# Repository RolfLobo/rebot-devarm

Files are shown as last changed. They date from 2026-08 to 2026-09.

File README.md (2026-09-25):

<div align="center">

# 🦾 reBot-DevArm

**The Open-Source Robotic Arm for Every Developer**

reBot-DevArm Banner

<a href="https://certification.oshwa.org/cn000024.html">OSHWA Certified</a>








**100% Open Source · Embodied AI · Full Hardware + Software Stack**

🌐 [Landing Page](https://279070161-sketch.github.io/reBot/) · 📚 [Tutorial Center](https://wiki.seeedstudio.com/robotics_page/) · ▶ [Online Demo](https://yang-ci.github.io/Rebot_Arm_AGV/)




[简体中文](README_zh.md) · [English](README.md) · [日本語](README_JP.md) · [français](README_Fr.md) · [Español](README_es.md)

</div>

---

## 📑 Contents

- [📖 Introduction](#introduction)
- [🛒 Get Your reBot Arm](#get-your-rebot-arm)
- [🚀 Try the Online Simulation](#try-the-online-simulation)
- [🗺️ Roadmap and Status](#roadmap-and-status)
- [⚙️ Hardware Specifications](#hardware-specifications)
- [🌟 Community Showcase](#community-showcase)
- [🧹 Optional Hardware](#optional-hardware)
- [🎓 Full-Stack Robotics Ecosystem](#full-stack-robotics-ecosystem)
- [🙌 Acknowledgments and Contributors](#acknowledgments-and-contributors)
- [📄 License](#license)
- [☎ Contact Us](#contact-us)

---

## 📖 Introduction

**reBot-DevArm** — the **reBot Arm B601-DM** and **reBot Arm B601-RS** — is a robotic arm project dedicated to lowering the barrier to learning Embodied AI. We believe in **true open source**: not just the code, but everything, released without reservation.

- 🦾 **Two arm models** — All design files for the **B601-DM (Damiao)** and **B601-RS (Robstride)**, two arms sharing the same appearance.
- 🛠️ **Hardware blueprints** — Source files for sheet-metal and 3D-printed parts.
- 🔩 **BOM list** — Detailed down to the spec and purchase link of every single screw.
- 💻 **Software & algorithms** — Python SDK, ROS1/2, Isaac Sim, LeRobot, and more.

## 🛒 Get Your reBot Arm

| Model | Official Store | Other Channels |
| :--- | :--- | :--- |
| **reBot Arm B601-DM** | [SeeedStudio Bazaar](https://www.seeedstudio.com/reBot-Arm-B601-DM-Assembled-Kit-with-Power-Supply-Bundle.html) | [Amazon](https://www.amazon.com/dp/B0H2TWVFSW) · [AliExpress](https://de.aliexpress.com/item/1005012108314029.html) |
| **reBot Arm B601-RS** | [SeeedStudio Bazaar](https://www.seeedstudio.com/reBot-Arm-B601-RS-Bundle-p-6898.html) | [AliExpress](https://www.aliexpress.us/item/3256812343811970.html?gatewayAdapt=deu2usa4itemAdapt) |

### B601-DM Kit Options

Five kit options are available at [SeeedStudio.com](https://www.seeedstudio.com/reBot-Arm-B601-DM-Bundle.html):

- **Arm Body Motor Kit** — Motors and wiring harnesses only.
- **Arm Body Structural Kit** — Mechanical structural components only.
- **Gripper Complete Kit** — Motors, wiring, and structure for the gripper.
- **Full Kit** — Complete arm body and gripper.
- **Pre-assembled Robotic Arm** — Fully assembled, ready to use.

> 💡 The kit does not include a power adapter or C-clamps as standard, since you may power it with batteries or mount it on a custom DIY base. Purchase a [power supply](https://www.seeedstudio.com/AC-DC-Power-Adapter-IEC-60320-C14-XT30-Female-24V-4-5A-1200mm-L190-W92-5-H36mm-p-6764.html) and [power cord](https://www.seeedstudio.com/reServer-AC-US-p-5052.html) separately, or see the Mean Well solution at the bottom of the [BOM](./hardware/reBot_B601_DM/readme.md#about-power-supply).

### B601-RS Kit Options

Two kit options are available at [SeeedStudio.com](https://www.seeedstudio.com/reBot-Arm-B601-RS-Assembled-Kit-with-Gripper-p-6865.html):

- **Full Kit** — Unassembled complete arm body and gripper.
- **Pre-assembled Robotic Arm** — Fully assembled, ready to use.

> 💡 We recommend the [Mean Well 48V 12.5A](https://www.amazon.com/sspa/click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) power supply for the RS model. For full performance, opt for a 48V 25A adapter.

### Leader Arm (Optional)

Purchase the [Leader Arm](https://www.seeedstudio.com/Star-Arm-102-p-6765.html?qid=P2U7IG_yskyak5m_1776415593315) and a [12V 10A power supply](https://www.seeedstudio.com/FY1209900-12V-10A-Power-Adapter-12V-10A-p-6496.html); the 12V DC adapter of the SO-ARM101 also works.

## 🚀 Try the Online Simulation

Experience the reBot Arm B601-RS MuJoCo digital twin directly in your browser — no installation required. Switch between the standard arm and AGV configurations, control joints and TCP, view the overhead and D405 wrist cameras, and run the automated put-away and stacking demos. The initial model download may take a moment; Chrome or Edge is recommended.

<p align="center">
  <a href="https://yang-ci.github.io/Rebot_Arm_AGV/"><strong>▶ Launch the reBot Arm Interactive Demo</strong></a>
</p>

## 🗺️ Roadmap and Status

We continuously maintain and adapt to mainstream robot development ecosystems. Below is our current progress and release plan.

### reBot Arm B601-DM

| Ecosystem | Status | Description | Documentation |
| :--- | :---: | :--- | :--- |
| Basic Motor Usage | ✅ Done | Motion control and API encapsulation | [Damiao Technology](https://wiki.seeedstudio.com/cn/damiao_series/) |
| STEP 3D Parts & BOM | ✅ Done | STEP files, parts BOM, and reference prices | [reBot Arm B601-DM BOM](./hardware/reBot_B601_DM/readme.md) |
| Real-Machine Performance Testing | ✅ Done | Performance under normal and extreme conditions | [Performance Testing](./hardware/reBot_B601_DM/performance_testing/Performance_Testing.md) |
| Assembly Video | ✅ Done | Ultra-detailed assembly steps and video | [Getting Started](https://wiki.seeedstudio.com/rebot_b601_dm_getting_started/) |
| Python SDK | ✅ Done | One-stop motor read/write & control (Robstride, Damiao, Mota, Gaoqing, Hexfellow…) | [Motorbridge](https://motorbridge.seeedstudio.com) · [Web UI](https://rebot-devarm.w0x7ce.eu/) |
| ROS2 Integration | ✅ Done | Kinematics, trajectory planning, gravity compensation | [ROS2 Guide](https://wiki.seeedstudio.com/rebot_arm_b601_dm_ros2_integration/) |
| Pinocchio Integration | ✅ Done | Forward/inverse kinematics and gravity compensation | [Pinocchio Guide](https://wiki.seeedstudio.com/rebot_arm_b601_dm_pinocchio_meshcat/) · [Repo](https://github.com/Seeed-Projects/reBotArm_control_py) |
| Isaac Sim Simulation | ✅ Done | USD models and simulated teleoperation | [Wiki](https://wiki.seeedstudio.com/rebot_arm_b601_dm_isaacsim/) |
| LeRobot Integration | ✅ Done | Hugging Face LeRobot training framework | [LeRobot Guide](https://wiki.seeedstudio.com/rebot_arm_b601_dm_lerobot/) |
| Depth Camera Integration | ✅ Done | YOLO + depth camera visual grasping demo | [Grasping Demo](https://wiki.seeedstudio.com/rebot_arm_b601_dm_grasping_demo/) |
| reSpeaker Voice Integration | ✅ Done | reSpeaker Flex 4-mic array, voice-driven control with spatial awareness | [Voice Control](https://wiki.seeedstudio.com/control_rebot_arm_using_voice_with_respeaker_flex/) |
| Latest Algorithms | ⏳ Planned | Mainstream algorithms updated progressively | Ongoing |
| Free Course Series | ⏳ Planned | A series of completely free courses | Ongoing |

#### Community Contributions

| Ecosystem | Author | Description | Repository |
| :--- | :---: | :--- | :--- |
| ROS2 (Humble), third-party integration, URDF / rebotarm_bringup | [@danieldoradotalaveron-rb](https://github.com/danieldoradotalaveron-rb) | 1. **Passive diagnostics monitor** (`rebotarm_monitor_ros2`) — `/diagnostics` overlay for `rqt_robot_monitor`, serial/CAN-aware aggregator;<br>2. **Safe park & shutdown** — capture rest pose on connect, slow return on shutdown or `/rebotarm/park`;<br>3. **Gravity compensation (smooth stop)** — MIT ramp-out to eliminate clack and jerk during pos/vel handoff;<br>4. **Gamepad teleop with IK/FK & safety** — end-effector control via IK, live RViz visualization (simulation-only test);<br>5. **D405 eye-in-hand TF** — Xacro under `end_link` for RViz visualization & TF only. | [rebotarm_monitor_ros2](https://github.com/danieldoradotalaveron-rb/rebotarm_monitor_ros2) · [reBotArmController_ROS2](https://github.com/danieldoradotalaveron-rb/reBotArmController_ROS2) |

### reBot Arm B601-RS

| Ecosystem | Status | Description | Documentation |
| :--- | :---: | :--- | :--- |
| Basic Motor Usage | ✅ Done | Motion control and API encapsulation | [Robstride](https://wiki.seeedstudio.com/cn/robstride_control/) |
| STEP 3D Parts & BOM | ✅ Done | STEP files, parts BOM, and reference prices | [reBot Arm B601-RS BOM](./hardware/reBot_B601_RS/README.md) |
| Getting Started | ✅ Done | Quick start for the B601-RS | [Getting Started](https://wiki.seeedstudio.com/rebot_b601_rs_getting_started/) |
| Assembly Video | ✅ Done | Ultra-detailed assembly steps and video | [Assembly Video](https://wiki.seeedstudio.com/rebot_b601_rs_getting_started/) |
| ROS2 (Humble) | ✅ Done | Kinematics, trajectory planning, gravity compensation, MoveIt2 | [ROS2 Guide](https://wiki.seeedstudio.com/rebot_arm_b601_rs_ros2_integration/) |
| LeRobot Integration | ✅ Done | Hugging Face LeRobot training framework | [LeRobot Guide](https://wiki.seeedstudio.com/rebot_arm_b601_rs_lerobot/) |
| Pinocchio Integration | ✅ Done | Forward/inverse kinematics and gravity compensation | [Pinocchio Guide](https://wiki.seeedstudio.com/rebot_arm_b601_rs_pinocchio_meshcat/) · [Repo](https://github.com/Seeed-Projects/reBotArm_control_py) |
| Depth Camera Integration | ✅ Done | YOLO + depth camera visual grasping demo | [Grasping Demo](https://wiki.seeedstudio.com/rebot_arm_b601_rs_grasping_demo/) |
| Embodied Agent Architecture | ✅ Done | Accepts natural-language commands (e.g. "pick up the red block"), auto-plans and executes grasping | [Design](https://wiki.seeedstudio.com/wrc_demo_tutorial/) · [Source](https://github.com/TheMoonAstronaut/wrc.git) |
| Isaac Sim Simulation | ✅ Done | USD models and simulated teleoperation | [DLI Course](https://www.seeedstudio.com/sim-to-real-with-seeed-rebot-and-nvidia-isaac) · [Repo](https://github.com/Seeed-Projects/reBot-Isaacsim) |
| Latest Algorithms | ⏳ Planned | Mainstream algorithms updated progressively | Ongoing |
| Free Course Series | ⏳ Planned | A series of completely free courses | Ongoing |

## ⚙️ Hardware Specifications

Designed for desktop Embodied AI applications, balancing payload and flexibility.

| Parameter | reBot Arm B601-DM | reBot Arm B601-RS |
| :--- | :--- | :--- |
| Payload | 1.5 kg | **2.5 kg** |
| Recommended Workspace | 70% of arm reach | 70% of arm reach |
| Max Reach | 767 mm | **754 mm** |
| Weight | **≈ 4.5 kg** | ≈ 6.7 kg |
| Repeatability | < 0.2 mm | < 0.2 mm |
| Degrees of Freedom | 6 DOF + 1 Gripper | 6 DOF + 1 Gripper |
| Supported Ecosystems | ROS1, ROS2, LeRobot, Pinocchio, Isaac Sim, Python SDK | ROS1, ROS2, LeRobot, Pinocchio, Isaac Sim, Python SDK |
| Supply Voltage | DC 24V | DC 48V |

## 🌟 Community Showcase

|  |  |  |  |  |
| :---: | :---: | :---: | :---: | :---: |
| <a href="https://www.kaggle.com/competitions/gemma-4-good-hackathon/writeups/new-writeup-1778618527713">GEM-4</a><br><sub>[GEM-4](https://www.kaggle.com/competitions/gemma-4-good-hackathon/writeups/new-writeup-1778618527713)</sub> | <a href="https://x.com/Linyan_Fu/status/2056383947341525180">Linyan Fu</a><br><sub>[Linyan Fu](https://x.com/Linyan_Fu/status/2056383947341525180) · [Apheth D Almeida](https://x.com/Apheth_DAlmeida/status/2053503164507476096)</sub> | <a href="https://x.com/DhruvDiddi/status/2046605015008383284">Dhruv Diddi</a><br><sub>[Dhruv Diddi](https://x.com/DhruvDiddi/status/2046605015008383284)</sub> | <a href="https://x.com/ed0henderson/status/2055076839002095743">Ed Henderson</a><br><sub>[Ed Henderson](https://x.com/ed0henderson/status/2055076839002095743)</sub> | Sameer<br><sub>Sameer</sub> |
| <a href="https://x.com/pham_blnh/status/2061994096374505710">Binh Pham</a><br><sub>[Binh Pham](https://x.com/pham_blnh/status/2061994096374505710)</sub> | <a href="https://www.instagram.com/reel/DY7Ny8OPjVu/?utm_source=ig_web_copy_link&igsh=NTc4MTIwNjQ2YQ==">FangTianChongHui</a><br><sub>[FangTianChongHui](https://www.instagram.com/reel/DY7Ny8OPjVu/?utm_source=ig_web_copy_link&igsh=NTc4MTIwNjQ2YQ==)</sub> | <a href="https://x.com/dong1505lin">Xense YaoLin Dong</a><br><sub>[Xense YaoLin Dong](https://x.com/dong1505lin)</sub> | <a href="https://x.com/ed0henderson/status/2055076839002095743">Ed Henderson</a><br><sub>[Ed Henderson](https://x.com/ed0henderson/status/2055076839002095743)</sub> | <a href="https://x.com/yoshikai_man/status/2079938975398244705">yoshikai_man</a><br><sub>[yoshikai_man](https://x.com/yoshikai_man/status/2079938975398244705)</sub> |
| <a href="https://github.com/lipengdong/hei-rebot-lift">hei-rebot-lift</a><br><sub>[hei-rebot-lift](https://github.com/lipengdong/hei-rebot-lift)</sub> | <a href="https://www.linkedin.com/posts/activity-7484390995862781952-TX4m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">Martin Kemka</a><br><sub>[Martin Kemka](https://www.linkedin.com/posts/activity-7484390995862781952-TX4m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)</sub> | <a href="https://www.linkedin.com/posts/kamil-buczy%C5%84ski-102843301_seeedstudio-rebotarm-seeedprojectofthemonth-ugcPost-7485297094715461633-RV_6/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">Kamil Buczyński</a><br><sub>[Kamil Buczyński](https://www.linkedin.com/posts/kamil-buczy%C5%84ski-102843301_seeedstudio-rebotarm-seeedprojectofthemonth-ugcPost-7485297094715461633-RV_6/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)</sub> | <a href="https://www.linkedin.com/posts/doradodaniel_computervision-spatialai-sim2real-share-7474727487374184448-NhwX/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">Daniel Dorado</a><br><sub>[Daniel Dorado](https://www.linkedin.com/posts/doradodaniel_computervision-spatialai-sim2real-share-7474727487374184448-NhwX/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)</sub> | <a href="https://www.linkedin.com/posts/asierarranz_nvidia-physicalai-isaaclab-ugcPost-7480271721942417408-YNwu/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">Asier</a><br><sub>[Asier](https://www.linkedin.com/posts/asierarranz_nvidia-physicalai-isaaclab-ugcPost-7480271721942417408-YNwu/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)</sub> |

<p align="center">
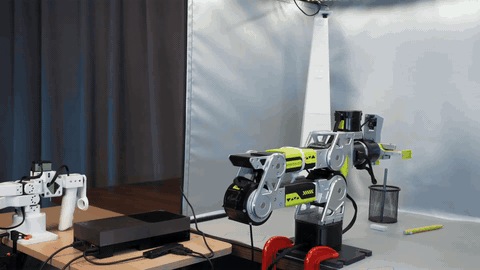
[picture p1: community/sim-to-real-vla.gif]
Sim-to-Real VLA Course
  <br>
  <sub><a href="https://www.seeedstudio.com/sim-to-real-with-seeed-rebot-and-nvidia-isaac">Seeed reBot Arm × NVIDIA Isaac — Sim-to-Real VLA Course</a></sub>
</p>

## 🧹 Optional Hardware

### Wrist Camera Mount

| 32×32 UVC | Intel D435i | Intel D405 & Gemini 305 | Gemini 2 |
| :--- | :--- | :--- | :--- |
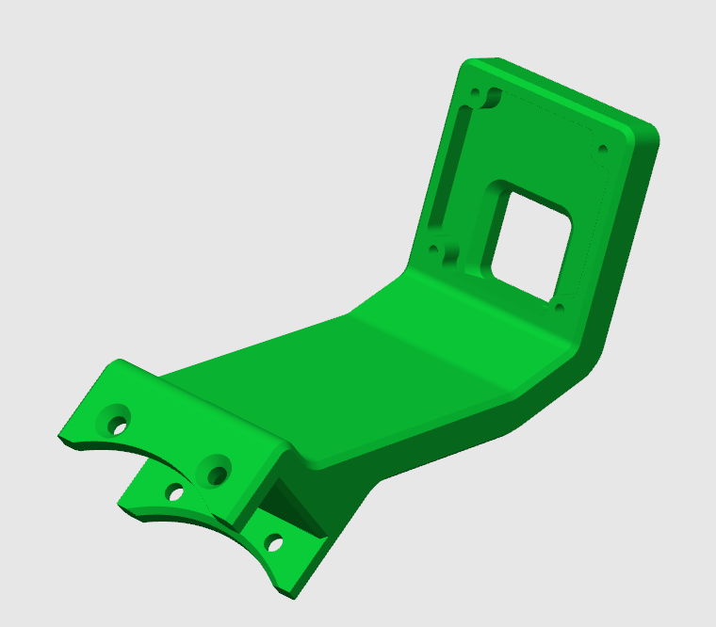
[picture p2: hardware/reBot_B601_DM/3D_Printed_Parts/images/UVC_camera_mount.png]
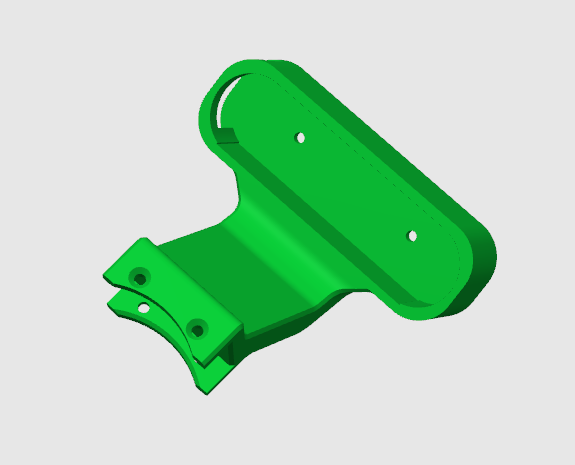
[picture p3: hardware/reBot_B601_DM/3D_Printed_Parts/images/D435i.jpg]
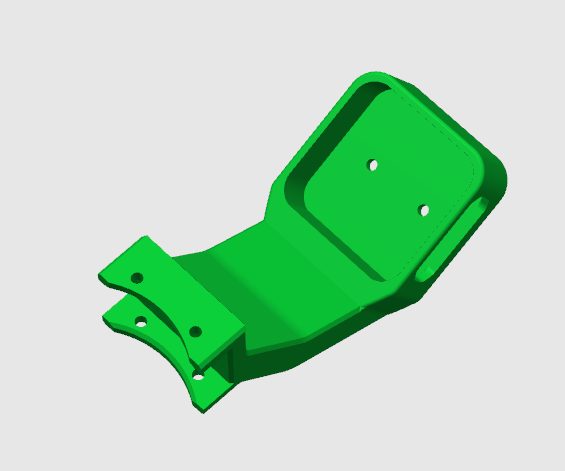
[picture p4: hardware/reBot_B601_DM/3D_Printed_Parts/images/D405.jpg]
|  |  |  |  |
| [STEP](hardware/reBot_B601_DM/3D_Printed_Parts/UVC32_mount.step) | [STEP](hardware/reBot_B601_DM/3D_Printed_Parts/D435_Gemini2_Mount.step) | [STEP](hardware/reBot_B601_DM/3D_Printed_Parts/D405_305_Mount.step) · [design notes](https://github.com/bowenszhu/rebot-b601-rs-d405-wrist-mount/tree/v1.0.0) | [STEP](hardware/reBot_B601_DM/3D_Printed_Parts/D435_Gemini2_Mount.step) |

### Leader Arm Compatibility

| Star Arm 102-LD | Open to compatibility integration |
| :--- | :--- |
|  | [Series Hub](https://fashionstar.com.hk/robot-arm/star-arm-102/) · [GitHub repo](https://github.com/servodevelop/Star-Arm-102) |

### DIY Soft Finger

| Soft Finger | Open to compatibility integration |
| :--- | :--- |
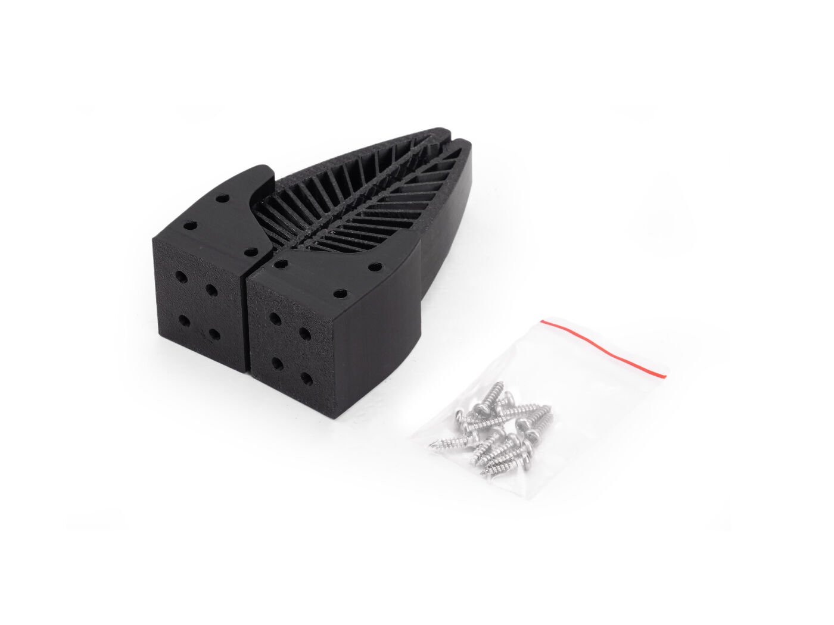
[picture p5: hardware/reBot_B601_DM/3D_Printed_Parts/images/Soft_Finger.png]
|  | Coming soon |
| [Finger Mount (ABS/PLA)](hardware/reBot_B601_DM/3D_Printed_Parts/Soft_Gripper_Mount.step) · [Finger (TPU 95+)](hardware/reBot_B601_DM/3D_Printed_Parts/Soft_Gripper_Finger.step) | Coming soon |

### Recommended Optional Hardware

| Category | Type | Preview | Product | Link |
| :--- | :--- | :--- | :--- | :--- |
| **Camera** | Depth Camera | Orbbec Gemini 2 | **Orbbec Gemini 2 3D Camera** | [Seeed Studio](https://www.seeedstudio.com/Orbbec-Gemini-2-3D-Camera-p-6464.html) |
| **Camera** | Depth Camera | Orbbec Gemini 336 | **Orbbec Gemini 336 Depth Camera** | [Seeed Studio](https://www.seeedstudio.com/Orbbec-Gemini-336-3D-Camera-3D-p-6662.html) |
| **Camera** | Depth Camera | Orbbec Gemini 335LG | **Orbbec Gemini 335LG 3D Camera** | [Seeed Studio](https://www.seeedstudio.com/Orbbec-Gemini-335LG-3D-Camera-p-6541.html) |
| **Camera** | Depth Camera | SLAMTEC Aurora S | **SLAMTEC Aurora S** | [Seeed Studio](https://www.seeedstudio.com/SLAMTEC-Aurora-S-AI-Integrated-Spatial-Perception-System-p-6669.html) |
| **Camera** | Depth Camera | Intel RealSense D435i | **Intel RealSense Depth Camera D435i** | [Seeed Studio](https://www.seeedstudio.com/Intel-RealSense-Depth-Camera-D435i-p-4423.html) |
| **Camera** | Depth Camera | RealSense D405 | **RealSense Depth Camera D405** | [Seeed Studio](https://www.seeedstudio.com/RealSense-D405-3D-Camera-p-6758.html) |
| **Camera** | Monocular Camera | Sensing SG3S-ISX031C-GMSL2F | **Sensing SG3S-ISX031C-GMSL2F 3MP GMSL2 Camera** | [Seeed Studio](https://www.seeedstudio.com/SG3S-ISX031C-GMSL2F-p-6245.html) |
| **Camera** | Monocular Camera | ET-S231 | **ET-S231 Megapixel 120° Wide-Angle 1080P USB Camera** | [Seeed Studio](https://www.seeedstudio.com/ET-S231-120-USB-Camera-p-6683.html) |
| **Microphone** | Mic Array | reSpeaker Flex XVF3800 | **reSpeaker Flex XVF3800 Circular-4 with XIAO ESP32S3** | [Seeed Studio](https://www.seeedstudio.com/reSpeaker-Flex-XVF3800-Circular-4-with-XIAO-ESP32S3-p-6739.html) |
| **Microphone** | Mic Array | reSpeaker XMOS XVF3800 | **reSpeaker XMOS XVF3800** | [Seeed Studio](https://www.seeedstudio.com/ReSpeaker-XVF3800-USB-Mic-Array-p-6488.html) |
| **Controller** | Edge Controller | reComputer J3011 | **reComputer J3011-Orin Nano 8GB** | [Seeed Studio](https://www.seeedstudio.com/reComputer-J3011-p-5590.html) |
| **Controller** | Edge Controller | Jetson AGX Thor | **NVIDIA Jetson AGX Thor Developer Kit** | [Seeed Studio](https://www.seeedstudio.com/NVIDIA-Jetson-AGX-Thor-Developer-Kit-p-9965.html) |

## 🎓 Full-Stack Robotics Ecosystem

reBot-DevArm is not just a robotic arm — it is a robotics learning community. The following general tutorials are shared for free:

**🖥️ Edge Computing & Master Control**

-  — AI inference & compute core
-  — general Linux dev environment
-  — low-power wireless control node

**📡 Sensors & Peripherals**

- **Motors & Servos** — [Damiao / Gogo / Robstride / Mita / Feite / Fashion Star](https://wiki.seeedstudio.com/robotics_page/)
- **Visual Perception** — [Depth cameras / LiDAR / vision algorithms](https://wiki.seeedstudio.com/robotics_page/)
- **Voice Interaction** — [reSpeaker mic arrays / voice control / spatial awareness (DoA)](https://wiki.seeedstudio.com/control_rebot_arm_using_voice_with_respeaker_flex/)
- **Motion & Attitude** — [IMU (6/9-axis) / gyroscopes / magnetometers](https://wiki.seeedstudio.com/Sensor_accelerometer/)
- **Comprehensive Kits** — [more robotics sensors & driver examples](https://wiki.seeedstudio.com/robotics_page/)

> 👉 **[Enter the Wiki Knowledge Base](https://wiki.seeedstudio.com/)** — all tutorials are free to view.

## 🙌 Acknowledgments and Contributors

The path of open source is never lonely. The reBot-DevArm project would not exist without the support of Seeed Studio, the global open-source community, and our hardware partners.

**🌍 Ecosystem & Software Support**

- [Seeed Studio](https://www.seeedstudio.com/) — hardware supply chain and technical support
- [Hugging Face LeRobot](https://github.com/huggingface/lerobot) — end-to-end robot learning framework
- [NVIDIA Isaac Sim](https://developer.nvidia.com/isaac/sim) — robot simulation and synthetic data platform

**⚙️ Core Hardware Partners**

- [Damiao Technology](https://www.damiaokeji.com/)
- [Robstride](https://robstride.com/)
- [Fashion Star](https://fashionstar.com.hk/wiki/)

**💡 Inspiration**

- [SO-ARM100](https://github.com/TheRobotStudio/SO-ARM100/tree/main)
- [Mobile ALOHA](https://github.com/tonyzhaozh/aloha)
- [Dummy-Robot (Zhihui Jun)](https://github.com/peng-zhihui/Dummy-Robot)
- [OpenArm](https://openarm.dev/)
- [I2RT](https://i2rt.com/)
- [TRLC-DK1](https://github.com/robot-learning-co/trlc-dk1)

**🎃 Prototype Contributors**

- SeeedStudio AI Robotics Team — Yaohui Zhu (yaohui.zhu@seeed.cc)
- SeeedStudio STU — Wentao Dong
- SeeedStudio STU — Weiwei Xu
- SeeedStudio Purchasing Department — Fengqun Peng

**👥 Contributors**

<p align="center"><a href="https://github.com/Seeed-Projects/reBot-DevArm/graphs/contributors">
  
</a></p>

*Coming soon — welcome to submit PRs and become a contributor!*

### ⭐ Star History

<p align="center">
<picture>
  <source media="(prefers-color-scheme: dark)" srcset="assets/star-history/star-history-dark.svg">
  <source media="(prefers-color-scheme: light)" srcset="assets/star-history/star-history-light.svg">
  
</picture>
</p>

## 📄 License

- **Hardware Design** © 2026 Seeed Studio Co., Ltd. — open sourced under [CERN-OHL-W-2.0](https://ohwr.org/cern_ohl_w_v2.txt)
- **Firmware Code** © 2026 Seeed Studio Co., Ltd. — open sourced under [Apache-2.0](https://www.apache.org/licenses/LICENSE-2.0)

### Rights and Restrictions

The reBot Arm project has always followed the core philosophy of **agility, openness, responsibility, and symbiosis** to serve the developer community. Our vision is to let every enthusiast master the hardware architecture and software principles of robotic arms, and experience cutting-edge embodied-intelligence algorithms through reBot.

For the first five months after launch, the project used the **CC BY-SA NC (Non-Commercial)** license, so developers could focus on iterating and improving the product during its early phase. After months of polishing, **effective May 11, 2026**, the project transitioned to the **CERN-OHL-W 2.0** open-source license, achieving **100% full-stack open source (hardware and software) with full commercial-compliance and usage rights for all scenarios**.

Hardware and software use different licenses — please confirm the terms applicable to the part you use.

| Item | Hardware (CERN-OHL-W-2.0) | Software SDK (Apache-2.0) |
| :--- | :--- | :--- |
| ✅ Commercial Use | ✅ Allowed | ✅ Allowed |
| ✅ Modification | ✅ Allowed | ✅ Allowed |
| ✅ Redistribution | ✅ Allowed | ✅ Allowed |
| ✅ Closed-source Integration | ❌ Conditional (see [CERN-OHL-W-2.0](https://ohwr.org/cern_ohl_w_v2.txt)) | ✅ Allowed (no disclosure required) |
| ⚠️ Copyright Retention | ✅ Required | ✅ Required |
| ⚠️ License Text Retention | ✅ Required | ✅ Required |
| ⚠️ Modification Notice | ✅ Required (date + description) | ✅ Required (description) |
| ⚠️ Patent Grant | ✅ Explicit | ✅ Explicit |
| ⚠️ Source Provision on Distribution | ✅ Must provide "Complete Source" | ❌ Not required |
| ⚠️ External/Closed Module Compatibility | ✅ Allowed (Weakly Reciprocal) | ✅ Fully allowed |
| 🔗 Relation to Other Components | Independent interface modules (External Material) may stay closed | No restrictions |
| 📄 Official Full Text | [CERN-OHL-W-2.0](https://ohwr.org/cern_ohl_w_v2.txt) | [Apache-2.0](https://www.apache.org/licenses/LICENSE-2.0) |

## ☎ Contact Us

- **Open-Source Progress & Technical Support** — Yaohui: yaohui.zhu@seeed.cc
- **Future Collaboration & Customization** — Elaine: elaine.wu@seeed.cc

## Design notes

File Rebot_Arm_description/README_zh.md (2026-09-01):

# ReBot Arm B601 机械描述复用包

<p align="center">
  <strong>
    <a href="./README_zh.md">简体中文</a> &nbsp;|&nbsp;
    <a href="./README.md">English</a>
  </strong>
</p>

`Rebot_Arm_description/` 汇总了 B601-RS 与 B601-DM 当前使用的 URDF 和 STL 资源，供 Web、RViz、ROS 2、MuJoCo 或其他机器人项目复用。

本目录采用相对路径，自带模型显示、URDF 碰撞和 MuJoCo 夹爪精细碰撞所需的网格。复制时建议保留整个版本目录，不要把 STL 全部摊平到同一层。

> 本目录是便于分发和复用的模型包，不是当前程序自动读取的唯一运行时目录。RS、DM 工程中的 ROS 2 和 MuJoCo 运行时资源位置见本文末尾“来源与同步”。

## 目录结构

```text
Rebot_Arm_description/
├── README.md
├── README_zh.md
├── RS/
│   ├── README.md
│   ├── README_zh.md
│   ├── urdf/
│   │   └── ReBot_Arm_RS.urdf
│   └── meshes/
│       ├── visual/             # 22 个：仅用于 RS 显示和配色
│       ├── shared/             # 10 个：RS URDF 显示与碰撞共用
│       └── mujoco_collision/   # 10 个：RS MuJoCo 夹爪精细碰撞
└── DM/
    ├── README.md
    ├── README_zh.md
    ├── urdf/
    │   └── ReBot_Arm_DM.urdf
    └── meshes/
        ├── visual/             # 30 个：仅用于 DM 显示和配色
        ├── collision/          # 10 个：仅用于 DM URDF 碰撞
        ├── shared/             # 4 个：DM 显示与 MuJoCo 碰撞共用
        └── mujoco_collision/   # 6 个：仅用于 DM MuJoCo 夹指碰撞
```

## 分类含义

| 目录 | 含义 | 修改后的影响 |
| --- | --- | --- |
| `visual/` | 只用于外观、颜色和结构细节 | 影响 Web/RViz/MuJoCo 外观，不应改变物理接触 |
| `collision/` | 只用于 URDF 碰撞检测 | 影响 MoveIt、碰撞检测及使用 URDF 碰撞体的仿真 |
| `shared/` | 在该版本中承担两种用途 | 修改前必须同时检查显示和碰撞结果 |
| `mujoco_collision/` | MuJoCo 夹爪精细接触网格 | 影响夹持、穿模、摩擦和抓取稳定性 |

分类依据是“文件在当前版本中的实际用途”，不是零件是否相同。因此，同一个 STL 在 RS 中可能位于 `mujoco_collision/`，在 DM 中可能位于 `shared/`。

## RS 与 DM 方案对比

| 项目 | B601-RS | B601-DM |
| --- | --- | --- |
| 主 URDF | `RS/urdf/ReBot_Arm_RS.urdf` | `DM/urdf/ReBot_Arm_DM.urdf` |
| 机械臂本体 | RS 专用连杆、CNC、电机和 PLA 网格 | DM 专用连杆及按材质拆分的网格 |
| 夹爪物理结构 | 与 DM 相同 | 与 RS 相同 |
| 夹爪 URDF 显示 | 每侧采用 `PLA + CNC` 两个较大的视觉件 | 每侧拆成黑色指爪、灰色滑块、黄色限位块、金属齿条 4 个材质件 |
| 夹爪 MuJoCo 精细碰撞 | 10 个 STL 全部只用于 MuJoCo | 同一套 10 个 STL，其中 6 个仅用于 MuJoCo，4 个同时参与 URDF 显示 |
| URDF 碰撞策略 | 10 个整件网格同时用于显示和碰撞，放在 `shared/` | 10 个独立碰撞整件，放在 `collision/` |
| 左右命名 | RS MJCF 因局部坐标约定，将 RS left 映射到 DM right 文件，反之亦然 | 使用 DM 的原始 left/right 命名 |

### 为什么 RS 是 10 个 `mujoco_collision`，DM 是 6 + 4

两端实际使用的是同一套 10 个夹爪精细碰撞 STL，文件内容已逐一校验一致：

- 6 个夹指分段：左右两侧各 `front / mid / rear`；
- 4 个滑块与限位块：左右两侧各 `carriage_grey / travel_stop_yellow`。

在 RS 中，这 10 个文件都不参与 URDF 外观，因此全部放在 `RS/meshes/mujoco_collision/`。

在 DM 中，4 个滑块和限位块还会作为 URDF 可见模型，所以放在 `DM/meshes/shared/`；剩余 6 个夹指分段只用于 MuJoCo，放在 `DM/meshes/mujoco_collision/`。这是用途分类差异，不是夹爪几何差异。

## URDF 路径约定

两个主 URDF 都使用相对路径，例如：

```xml
<mesh filename="../meshes/visual/example.stl" />
```

因此：

- 必须保留 `urdf/` 与 `meshes/` 的相对层级；
- 移动或重命名网格目录时，必须同步修改 URDF；
- Linux 文件名区分大小写，`.STL` 与 `.stl` 不应随意互换；
- 模型尺寸以米为单位，关节角以弧度为单位，不要在加载器中重复缩放。

## 如何复用

### Web / Three.js

将整个 `RS/` 或 `DM/` 目录放到静态服务器可访问的位置，从对应的 `urdf/ReBot_Arm_*.urdf` 加载。服务器必须允许继续访问相邻的 `meshes/` 子目录。

只做显示时，URDF 会自动加载 `visual/` 和 `shared/` 中引用的网格。不要把 DM 的材质分件直接叠加到 RS 的 `PLA + CNC` 视觉件上，否则可能出现重叠闪烁、颜色变亮和重复面。

### ROS 2 / RViz / MoveIt

建议把所选版本复制到 ROS package 的 `description/` 下，并将相对路径改成：

```text
package://<package_name>/description/meshes/...
```

同时确认 `setup.py` 或 `CMakeLists.txt` 会安装所有 URDF 和 STL。RViz 只负责显示；MoveIt 是否使用碰撞网格取决于加载的 robot description。

### MuJoCo

本目录提供 MuJoCo 需要的 STL，但不包含完整 MJCF 场景。复用时应在 MJCF `<compiler meshdir="...">` 或 `<mesh file="...">` 中指向：

- RS：`RS/meshes/mujoco_collision/` 中的 10 个精细碰撞件；
- DM：`DM/meshes/mujoco_collision/` 的 6 个分段件，加上 `DM/meshes/shared/` 的 4 个滑块与限位块。

不要用完整夹指的单一凸包替换这些分段网格，否则可能重新出现闭合穿模、接触面过大或夹持不稳定。

## 修改与同步规则

1. **只改颜色**：优先修改 URDF `<material>` 或渲染器的 roughness/metalness，不要改变碰撞 STL。
2. **改视觉几何**：检查 Web、RViz 与 MuJoCo 外观；不要默认视觉变化会自动同步到碰撞模型。
3. **改 URDF 碰撞**：重新验证 MoveIt 自碰撞、关节全行程和末端附近接触。
4. **改夹爪精细碰撞**：RS、DM 共用同一套几何，应同步更新两端并重新验证抓取、闭合和释放。
5. **改左右夹指名称或坐标**：同步检查 RS 的左右反向映射和 MJCF 中的 `pos/quat`，不能只重命名文件。
6. **发布前**：确认所有 URDF 引用存在、XML 可解析，并在 Linux 上检查文件名大小写。

## 来源与同步

当前运行时源文件位于：

```text
# RS
rebotarm_ros2_RS/src/rebotarm_bringup/description/
rebotarm_ros2_RS/src/rebotarm_mujoco_rs/models/

# DM（位于 DM 仓库）
reBotArm_ros2_DM/src/rebotarm_bringup/description/
reBotArm_ros2_DM/src/rebotarm_mujoco/models/
```

`Rebot_Arm_description/` 是面向复用者整理的自包含副本。运行时源模型发生变化后，应同步更新这里的对应 URDF/STL，并重新执行引用完整性和仿真验证。

## 选择建议

- 需要 B601-RS 外观、ROS 模型或 RS 工程集成：使用整个 `RS/`。
- 需要 B601-DM 材质分件、ROS 模型或 DM 工程集成：使用整个 `DM/`。
- 只复用夹爪 MuJoCo 碰撞：两端几何相同，可任选一套，但必须保留全部 10 个分件及正确的左右坐标映射。
- 不确定需要哪些文件：复制整个版本目录最安全，文件分类主要用于理解和维护，不要求使用者手动挑选。

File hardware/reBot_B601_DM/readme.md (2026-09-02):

# 🤖 reBot DevArm Open Source Hardware Specification

<p align="center">
  reBot-DevArm Banner
</p>
<p align="center">
  <strong>
    <a href="./readme_zh.md">简体中文</a> &nbsp;|&nbsp;
    <a href="./readme.md">English</a> &nbsp;|&nbsp;
    <a href="./readme_jp.md">日本語</a>&nbsp;|&nbsp;
    <a href="./readme_fr.md">français</a>&nbsp;|&nbsp;
    <a href="./readme_es.md">Español</a>
  </strong>
</p>

| Date | Version | File Name | Changelog |
|---|---|---|---|
|  2026-03-31 | v1.0 |  reBot_B601_DM_v1.0_20260331.step  | Initial upload |
|  2026-04-25 | v1.1 |  reBot_B601_DM_v1.1_20260425.step  | Added Cable Restraint for the 3 end joint motors to prevent loosening and disconnection. Fixed Joint 1 model from 4310 to 4340P. Added CNC part 02_Base_Reinforcement_Part.step at the bottom to enhance base rigidity. |

This BOM is for the reBot Arm B601 DM robotic arm, which uses Damiao 43 series motors. The other version, reBot Arm B601 RS, uses RobStride motors; [see the BOM here](../reBot_B601_RS/README.md).

# 📦 File Structure
*   3D_Printed_Parts/: Step files for all 3D printed parts.
*   Metal_Parts/: Step files for all CNC machined metal parts.
*   Purchased_Parts/: Step files for all purchased components.
*   reBot_B601_DM_v1.1_20260415.step: Full robotic arm assembly file.

# 🛒[Gets All Parts](https://www.seeedstudio.com/reBot-Arm-B601-DM-Bundle.html)
- We offer five kit options:
  - **Arm Body Motor Kit**: Includes only motors and wiring harnesses for the robotic arm.
  - **Arm Body Structural Kit**: Includes only mechanical structural components.
  - **Gripper Complete Kit**: Includes motors, wiring harnesses and structural components for the gripper.
  - **Full Kit**: Includes the complete set of the robotic arm body and gripper.
  - **Pre‑assembled Robotic Arm**: Fully assembled finished robotic arm.

# 📊 Bill of Materials (BOM)

> [!WARNING]
> Declaration: The published BOM does **not** represent the final shipping version from Seeed. This open-source v1.1 is optimized for developers to reproduce at minimal cost, with some non-essential details simplified.
> The final Seeed production version will include metal laser engraving for foolproofing, some 3D printed parts will be replaced with metal for durability, clearances and machining tolerances will be adjusted for factory variation (balancing precision and cost), and custom wiring (e.g., braided sleeve protection) will be added at extra cost. However, the mechanical structure remains identical.

---

## 🖨️ 3D Printed Parts

| Part Description | Image | File Name | Material | Qty | Notes |
|---|---|---|---|---|---|
| Robotic Arm Base Platform |  | 01_BASE_Plate.step | Bambu ABS Black | 1 | 0.4 nozzle, 0.2 layer height, 30% infill |
| Robotic Arm Base Link |  | 01_BASE_Link.step | Bambu ABS Black | 1 | 0.4 nozzle, 0.2 layer height, 30% infill |
| Upper Arm Left Filler |  | 01_Upper_Arm_Fuller_L.step | Bambu PLA Black & Green | 1 | 0.4 nozzle, 0.2 layer height, 15% infill |
| Upper Arm Right Filler |  | 01_Upper_Arm_Fuller_R.step | Bambu PLA Black & Green | 1 | 0.4 nozzle, 0.2 layer height, 15% infill |
| Upper Arm Center Filler |  | 01_Upper_Arm_Fuller_M.step | Bambu ABS Black | 1 | 0.4 nozzle, 0.2 layer height, 30% infill |
| Upper Arm Horizontal Limit Block |  | 01_Upper_Arm_Limit.step | Bambu ABS Black | 1 | 0.4 nozzle, 0.2 layer height, 30% infill |
| Arm Handle |  | 01_Arm_Handle.step | Bambu ABS Black | 1 | 0.4 nozzle, 0.2 layer height, 30% infill |
| Lower Arm Left Filler |  | 01_Lower_Arm_Filler_L.step | Bambu PLA Black & Green | 1 | 0.4 nozzle, 0.2 layer height, 15% infill |
| Lower Arm Right Filler |  | 01_Lower_Arm_Filler_R.step | Bambu PLA Black & Green | 1 | 0.4 nozzle, 0.2 layer height, 15% infill |
| Lower Arm Center Filler |  | 01_Lower_Arm_Filler_M.step | Bambu ABS Black | 1 | 0.4 nozzle, 0.2 layer height, 30% infill |
| Upper Arm Cover |  | 01_Upper_Arm_Cover.step | Bambu PLA Green | 1 | 0.4 nozzle, 0.2 layer height, 15% infill |
| Lower Arm Cover |  | 01_Lower_Arm_Cover.step | Bambu PLA Green | 1 | 0.4 nozzle, 0.2 layer height, 15% infill |
| Motor 5 Protection Cover |  | 01_Motor_Cover.step | Bambu ABS Black | 1 | 0.4 nozzle, 0.2 layer height, 30% infill |
| Gripper Horizontal Limit |  | 01_Lower_Arm_Limit.step | Bambu PLA Green | 1 | 0.4 nozzle, 0.2 layer height, 15% infill |
| Gripper Slider Support Bracket |  | 01-Rail-Bracket.step | Bambu PLA Green | 1 | 0.4 nozzle, 0.2 layer height, 15% infill |
| Gripper Finger |  | 01_Finger.step | Bambu ABS Black | 2 | 0.4 nozzle, 0.2 layer height, 45% infill |
| Motor 5 Cable Restraint |  | 01_Joint5_Cable Restraint_A.step | Bambu PLA Green | 1 | 0.4 nozzle, 0.2 layer height, 15% infill |
| Motor 6 & 7 Cable Restraint A |  | 01_Joint6_7_Cable Restraint_A.step | Bambu ABS Black | 2 | 0.4 nozzle, 0.2 layer height, 30% infill |
| Motor 6 & 7 Cable Restraint B |  | 01_Joint6_7_Cable Restraint_B.step | Bambu ABS Black | 2 | 0.4 nozzle, 0.2 layer height, 30% infill |
| - | Reference Price | Average **50$** | | | Price varies by material cost and printing time |

Long-term dragging of Wiring Harness 1 may abrade the motor connector and result in poor electrical contact. Printing the parts listed below can mitigate this risk.

| Part Description | Image | File Name | Material | Qty | Remarks |
| ---- | ---- | ---- | ---- | ---- | ---- |
| Wiring Harness Clips for Two Sides of Motor 1 |  | `DM_Motor1_wiring_harness_clip.stp` | Bambu Lab Black ABS | 2 | 0.4 mm nozzle, 0.2 mm layer height, 30% infill |

## 📷 Compatible Camera Mount

| Part Description | Image | File Name | Material | Qty | Notes |
|---|---|---|---|---|---|
| [Orbbec Gemini2](https://www.seeedstudio.com/Orbbec-Gemini-2-3D-Camera-p-6464.html) |  | [`D435_Gemini2_Mount.step`](./3D_Printed_Parts/D435_Gemini2_Mount.step) | Bambu ABS Black | 1 | 0.4mm Nozzle, 0.2mm Layer Height, 30% Infill |

### 🧩 Printing Recommendations
- Layer height: 0.2 mm
- Nozzle: 0.4 mm
- Supports: Add as needed
- Materials: High-temperature and load-bearing parts use ABS with 30–80% infill; may also use nylon or carbon-fiber reinforced materials. Cosmetic parts use PLA with 15% infill.
- Recommended materials for load-bearing parts:

---

## 🔩 CNC Machined Metal Parts

> [!WARNING]
> Some parts that can be replaced with 3D printing are noted in the remarks, which can significantly reduce costs.

| Part Description | Image | File Name | Material | Qty | Machining | Notes |
|---|---|---|---|---|---|---|
| Motor 1 Bearing Mount |  | 02_Base_Reinforcement_Part.step | Aluminum Alloy 5052 | 1 | CNC | Can be 3D printed in ABS with high infill to reduce cost |
| Motor 1 Rotation Axis |  | 02_Arm_Yaw_Limit.step | Aluminum Alloy 5052 | 1 | CNC | Added yaw angle motion limit |
| Motor 2–5 Front Spacer |  | 02_Motor_Front_Spacer.step | Aluminum Alloy 5052 | 4 | CNC | Can be 3D printed in ABS with 30% infill |
| Motor 2–4 Rear Spacer |  | 02_Motor_Back_Spacer.step | Aluminum Alloy 5052 | 3 | CNC | |
| Motor 2–4 Rear Flange |  | 02_FLANGE.step | Aluminum Alloy 5052 | 3 | CNC | |
| Wrist Motor 5 Bracket |  | 02_Wrist_Bracket.step | Aluminum Alloy 5052 | 1 | CNC | |
| Gripper Connector A |  | 02_Gripper_Connector_A.step | Aluminum Alloy 5052 | 1 | CNC | |
| Gripper Connector B |  | 02_Gripper_Connector_B.step | Aluminum Alloy 5052 | 1 | CNC | |
| Gripper Slider Metal Bracket |  | 02_Slider_Bracket.step | Aluminum Alloy 5052 | 1 | CNC | Can be 3D printed in ABS with high infill, not recommended for long-term use |
| Slider to Gripper Extension |  | 02_Slider_Extension.step | Aluminum Alloy 5052 | 2 | CNC | |
| Upper-Lower Arm Link Left |  | 02_Lower_Upper_Link_L.step | Aluminum Alloy 5052 | 1 | CNC | |
| Upper-Lower Arm Link Right |  | 02_Lower_Upper_Link_R.step | Aluminum Alloy 5052 | 1 | CNC | |
| Lower Arm-Wrist Link Left |  | 02_Lower_Wrist_Link_L.step | Aluminum Alloy 5052 | 1 | CNC | |
| Lower Arm-Wrist Link Right |  | 02_Lower_Wrist_Link_R.step | Aluminum Alloy 5052 | 1 | CNC | |
| Gear Connector |  | 02_Gear_Connector.step | Aluminum Alloy 5052 | 1 | CNC | |
| Rack |  | 02_Rack.step | Aluminum Alloy 5052 | 2 | CNC | |
| Link 1 |  | 03_Link1.step | Aluminum Alloy 5052 | 1 | CNC + Sheet Metal | |
| Link 2 |  | 03_Link2.step | Aluminum Alloy 5052 | 2 | CNC + Sheet Metal | |
| Link 3 Left |  | 03_Link3_L.step | Aluminum Alloy 5052 | 1 | CNC + Sheet Metal | |
| Link 3 Right |  | 03_Link3_R.step | Aluminum Alloy 5052 | 1 | CNC + Sheet Metal | |
| Link 5 |  | 03_Link5.step | Aluminum Alloy 5052 | 1 | CNC + Sheet Metal | |
| - | Market Reference Price | Average **250$** | | | Price varies by aluminum cost, tolerance requirements, lead time |

### 🧩 Machining Specifications
- Key dimension tolerance: ±0.02 mm GB/T1840-M
- Surface finish: Anodizing / Sandblasting
- Mating parts recommended: H7 / interference fit
---

## 🛒 Purchased Parts (Standard Parts)

> [!WARNING]
> Since everyone will need to assemble and tighten the screws themselves, standard hex socket screws have been selected. After prolonged operation, the screws may loosen, which will affect the precision of the robotic arm. For this reason, you are required to purchase additional hot melt glue to perform thread locking on the screws at each joint.

If you have a power drill or similar tools, you may choose to buy lock washers or thread-locking screws instead. However, **it is extremely important** that you use the lowest torque setting when using an electric screwdriver to avoid thread stripping, which will result in irreversible damage.

  | Name | Specification / Model | Quantity | Reference Price | Notes |
  |------|----------|------|----------|------|
  | Brushless motor | DM4310(V4) | 4 | 120 $/unit | [SeeedStudio](https://www.seeedstudio.com/Damiao-4310-Actuator-Motor-p-6823.html) |
  | Brushless motor | DM4340P(V4) | 3 | 175 $/unit |  [SeeedStudio](https://www.seeedstudio.com/DM4340P-Actuator-p-6663.html)  |
  | CAN-USB driver board |  | 1 | 15 $/unit |   [SeeedStudio](https://www.seeedstudio.com/DM-CAN-USB-Driver-Borad-p-6706.html)   |
  | Bearing | 6707ZZ | 1 | 13 $/unit | [Amazong](https://www.amazon.com/uxcell-35x44x5mm-Shielded-Precision-Lubricated/dp/B0D6WBMW3F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) |
  | Bearing | 6803ZZ | 3 | 13 $/unit | [Amazong](https://www.amazon.com/uxcell-17x26x5mm-Shielded-Precision-Lubricated/dp/B0D54JSWBZ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) |
  | Bearing | AXK5578 | 1 | 12 $/unit | [Amazong](https://www.amazon.com/PZRT-AXK5578-Thrust-Bearings-Washers/dp/B0B3M3RZGW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) |
  | Linear rail | MGN9-170mm | 1 | 23 $/unit | [Amazong](https://www.amazon.com/uxcell-Sliding-Carriage-Bearing-Printers/dp/B0D54L45WM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) |
  | Slider block | MGN9 | 2 | 10 $/unit | [Amazong](https://www.amazon.com/uxcell-Bearing-Sliding-Carriage-Anti-Fall/dp/B0D9QBQDKB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) |
  | Gear | Module 1, boss type, 16 teeth, 6 mm bore | 1 | 44$/unit | [Amazong](https://www.amazon.com/Module-15-Teeth-Finished-Perforation/dp/B0GDSR1LKM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)  |
  | Silicone pad | 30x9x2mm | 1 | 10 $ | [Amazong](https://www.amazon.com/Self-Adhesive-Anti-Sliding-Anti-Scratch-Protectors-Appliances/dp/B0F9KVYXFZ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) |
  | Screw | HM3-12mm screw | 14+ |  | [Amazong](https://www.amazon.com/BNUOK-120pcs-Stainless-Threads-Spanner/dp/B0DJQGMQZM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) |
  | Screw | HM3-25mm screw | 14+ |  | [Amazong](https://www.amazon.com/BNUOK-120pcs-Stainless-Threads-Spanner/dp/B0DJQFGRPQ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)  |
  | Screw | HM3-6mm screw | 16+ |  | [Amazong](https://www.amazon.com/BNUOK-120pcs-Stainless-Threads-Spanner/dp/B0DJQG5YLF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)  |
  | Screw | HM4-75mm set screw | 4+ |  | [Amazong](https://www.amazon.com/iexcell-Partially-Threaded-Thread-Socket/dp/B0DR1NX178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)  |
  | Screw | KM3*12mm screw | 30+ |  |  [Amazong](https://www.amazon.com/Uxcell-a16011300ux0872-M3x12mm-Carbon-Countersunk/dp/B01E6EIC2S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) |
  | Screw | KM3*16mm screw | 34+ |  | [Amazong](https://www.amazon.com/Uxcell-a16011300ux0872-M3x12mm-Carbon-Countersunk/dp/B01E6EIC2S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)  |
  | Screw | KM3*7mm screw | 76+ |  |[Amazong](https://www.amazon.com/Uxcell-a16011300ux0872-M3x12mm-Carbon-Countersunk/dp/B01E6EIC2S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)   |
  | Screw | KM3*9mm screw | 31+ |  |[Amazong](https://www.amazon.com/Uxcell-a16011300ux0872-M3x12mm-Carbon-Countersunk/dp/B01E6EIC2S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)   |
  | Screw | KM3*8mm Socket Micro Profile Head Screw | 31+ |  |[Amazong](https://www.amazon.com/SMALLRIG-Screw-Screws-12pcs-Pack/dp/B01MS60KSY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)   |
  | Screw | KA3*12mm | 72+ |  | [Amazong](https://www.amazon.com/uxcell-Phillips-Tapping-Screws-Silver/dp/B01MXSS95N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)  |
  | Dowel pin | M4*8mm | Several |  | [Amazong](https://www.amazon.com/HARFINGTON-Stainless-Cylindrical-Furniture-Installation/dp/B0F6CWL4MP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)  |
  | Dowel pin | M4*12mm | Several |  | [Amazong](https://www.amazon.com/HARFINGTON-Stainless-Cylindrical-Furniture-Installation/dp/B0F6CWL4MP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)  |
  | Screwdriver set | Hex key set | 1 | 16$  | [Amazong](https://www.amazon.com/Amazon-Basics-Ratcheting-Electronics-Screwdriver/dp/B07V4TFWFZ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)  |
  |  | XT30 2+2 350mm | 2 | 4 $/cable | Both ends angled |
  |  | XT30 2+2 350mm | 1 | 4 $/cable | One angled end and one straight end |
  |  | XT30 2+2 200mm | 3 | 4 $/cable | Both ends angled |
  |  | XT30 2+2 200mm | 1 | 3 $/cable | Both ends straight |

### About Fixing
You may modify your base freely based on the 3D printed parts we provide. You can also use G-clamps according to the thickness of your desktop.

  | Name | Specification / Model | Quantity | Reference Price | Notes |
  |------|----------|------|----------|------|
  | Woodworking clamp | 6-inch G clamp | 2 | 20 $/unit | [Amazong](https://www.amazon.com/gp/aw/d/B092J1YW2M/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) |

### About Power Supply
The robotic arm is shipped without a power supply by default. You may connect your own battery, or purchase a reliable 24V 14.6A MeanWell power supply made in Taiwan. Additionally, you will need to buy a three-pin plug compliant with local standards and a wiring harness with XT30 female connector.

#### Consumables BOM

| Name | Specification | Qty | Reference Price | Notes | Image |
|:---|:---|:---:|:---:|:---|:---:|
| Power Supply | LRS-350-24 (24V 14.6A) | 1 | $27.35 | [amazon](https://www.amazon.com/MEAN-WELL-LRS-350-24-350-4W-Switchable/dp/B013ETVO12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) |  |
| Power Cord | US Standard AC Cable | 1 | $4.49 | [amazon](https://www.amazon.com/LIFEPOE-Power-3-3ft-Black-3-Prong/dp/B0FK4KPW2G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) |  |
| Output Port | XT60E Fixed Female Connector; XT60E Female + Lug - 10cm; 4mm Lug Hole | 1 | $9.99 | [amazon](https://www.amazon.com/LINSYRC-XT60E-F-Connector-Battery-Quadcopter/dp/B0CQK1P1DP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) |  |
| Power AC Wiring | 1.5mm²; Red, Blue, Yellow x1 each(User must crimp terminals to the wire — pre-crimped leads not included.); 10CM | 3 | $0.99 | [aliexpress](https://www.aliexpress.com/item/1005008648016252.html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) |  |
| 3-in-1 IEC Inlet Socket | Quick-connect type with red switch (Dual Nuts) | 1 | $1.98 | [aliexpress](https://www.aliexpress.com/item/1005005962021242.html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) |  |
| XT30 to XT60 adapter cable plug | XT30U female to XT60 male | 1 | 8.99$ | [amazon](https://www.amazon.com/dp/B0BY8PSHK6?th=1) |  |
| 304 Stainless Steel Phillips Countersunk Head Screw | M4x6 | 6 | $0.37 | / | / |
| 304 Stainless Steel Phillips Countersunk Head Screw | M3x8 | 2 | $0.36 | / | / |
| 304 Stainless Steel Phillips Pan Head Screw | M3x8 | 2 | $0.32 | / | / |
| Hex Nut | M3x2.5 | 2 | 2.10 CNY | / | / |

#### Printed Parts BOM

| Name | Image | Qty | Notes |
|:---|:---|:---:|:---|
| [Front Cover](./3D_Printed_Parts/DM-power-Top%20Cover.stp) |  | 1 | PLA, 0.4mm Nozzle, 0.2mm Layer Height, 30% Infill |
| [Rear Cover](./3D_Printed_Parts/DM-power-Bottom%20Cover.stp) |  | 1 | PLA, 0.4mm Nozzle, 0.2mm Layer Height, 30% Infill |
| [Front Cover Slider](./3D_Printed_Parts/DM-power-Top%20Cover-Sliding%20Cover.stp) |  | 1 | PLA, 0.4mm Nozzle, 0.2mm Layer Height, 30% Infill |

#### Power Supply Assembly

The power supply assembly is divided into two main sections: the Front Cover and the Rear Cover.

##### 1. Front Cover Assembly

| Step | Operation Instructions | Image | Remarks |
|:---:|---|---|---|
| 1-1 | Prepare the parts and printed components required for front shell assembly |  | Check that all parts are complete |
| 1-2 | Wiring sequence instructions for each part; assemble according to the wiring sequence | <br> | Connect strictly according to the wiring sequence |
| 1-3 | Install the XT60 connector |  | Secure with 304 stainless steel Phillips countersunk head screws M3x8 and hex nuts M3x2.5 |
| 1-4 | Install the 3-in-1 IEC socket |  | Secure the 3-in-1 IEC socket with 304 stainless steel Phillips pan head screws M3x8 |
| 1-5 | Internal wiring of the front shell | <br> | Check connections against the wiring sequence diagram |
| 1-6 | Secure both sides of the front shell and the power supply |  | M4x6 304 stainless steel Phillips countersunk head screws x2 |
| 1-7 | Install the sliding cover |  | Push in from the bottom of the power supply |
| 1-8 | Secure the sliding cover |  | M4x6 304 stainless steel Phillips countersunk head screws x2 |

---

##### 2. Rear Shell Assembly

| Step | Operation Instructions | Image | Remarks |
|:---:|---|---|---|
| 2-1 | Prepare the parts and printed components required for rear shell assembly |  | Check accessories for completeness |
| 2-2 | Assemble the rear shell with the power supply |  | Align the position |
| 2-3 | Secure both sides of the rear shell and the power supply |  | M4x6 304 stainless steel Phillips countersunk head screws x2 |

---

##### 3. Overall Completion

| Step | Operation Instructions | Image | Remarks |
|:---:|---|---|---|
| 1 | Power supply solution assembly completed |  | Check that all screws are tightened |

---

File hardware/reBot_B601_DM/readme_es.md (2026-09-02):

# 🤖 Especificación de hardware de código abierto de reBot DevArm

<p align="center">
  Banner de reBot-DevArm
</p>
<p align="center">
  <strong>
    <a href="./readme_zh.md">简体中文</a> &nbsp;|&nbsp;
    <a href="./readme.md">English</a> &nbsp;|&nbsp;
    <a href="./readme_jp.md">日本語</a>&nbsp;|&nbsp;
    <a href="./readme_fr.md">français</a>&nbsp;|&nbsp;
    <a href="./readme_es.md">Español</a>
  </strong>
</p>

| Fecha | Versión | Nombre del archivo | Registro de cambios |
|---|---|---|---|
|  2026-03-31 | v1.0 |  reBot_B601_DM_v1.0_20260331.step  | Subida inicial |
|  2026-04-25 | v1.1 |  reBot_B601_DM_v1.1_20260425.step  | Se añaden sujeciones de cables para los 3 motores de las articulaciones del extremo, para evitar que se aflojen y se desconecten. Se corrige el modelo de la articulación 1 de 4310 a 4340P. Se añade la pieza CNC 02_Base_Reinforcement_Part.step en la parte inferior para reforzar la rigidez de la base. |

Esta BOM corresponde al brazo robótico reBot Arm B601 DM, que utiliza motores de la serie 43 de Damiao. La otra versión, el reBot Arm B601 RS, utiliza motores RobStride; [consulta su BOM aquí](../reBot_B601_RS/README.md).

# 📦 Estructura de archivos
*   3D_Printed_Parts/: archivos STEP de todas las piezas impresas en 3D.
*   Metal_Parts/: archivos STEP de todas las piezas metálicas mecanizadas por CNC.
*   Purchased_Parts/: archivos STEP de todos los componentes comprados.
*   reBot_B601_DM_v1.1_20260425.step: archivo del ensamblaje completo del brazo robótico.

# 🛒[Consigue todas las piezas](https://www.seeedstudio.com/reBot-Arm-B601-DM-Bundle.html)
- Ofrecemos cinco opciones de kit:
  - **Kit de motores del cuerpo del brazo**: incluye solo los motores y los arneses de cableado del brazo robótico.
  - **Kit estructural del cuerpo del brazo**: incluye solo los componentes estructurales mecánicos.
  - **Kit completo de la pinza (gripper)**: incluye los motores, los arneses de cableado y los componentes estructurales de la pinza.
  - **Kit completo**: incluye el conjunto completo del cuerpo del brazo robótico y la pinza.
  - **Brazo robótico premontado**: brazo robótico acabado y totalmente montado.

# 📊 Lista de materiales (BOM)

> [!WARNING]
> Aviso: la BOM publicada **no** representa la versión final que envía Seeed. Esta v1.1 de código abierto está optimizada para que los desarrolladores puedan reproducirla con el mínimo coste, con algunos detalles no esenciales simplificados.
> La versión final de producción de Seeed incluirá grabado láser en el metal para evitar errores de montaje (poka-yoke), algunas piezas impresas en 3D se sustituirán por metal para mayor durabilidad, las holguras y tolerancias de mecanizado se ajustarán a la variabilidad de fábrica (equilibrando precisión y coste) y se añadirá cableado personalizado (p. ej., protección con malla trenzada) con coste adicional. No obstante, la estructura mecánica es idéntica.

---

## 🖨️ Piezas impresas en 3D

| Descripción de la pieza | Imagen | Nombre del archivo | Material | Cant. | Notas |
|---|---|---|---|---|---|
| Plataforma base del brazo robótico |  | 01_BASE_Plate.step | ABS Bambu Lab negro | 1 | boquilla de 0.4 mm, altura de capa de 0.2 mm, relleno del 30% |
| Eslabón de la base del brazo robótico |  | 01_BASE_Link.step | ABS Bambu Lab negro | 1 | boquilla de 0.4 mm, altura de capa de 0.2 mm, relleno del 30% |
| Relleno izquierdo del brazo superior |  | 01_Upper_Arm_Fuller_L.step | PLA Bambu Lab negro y verde | 1 | boquilla de 0.4 mm, altura de capa de 0.2 mm, relleno del 15% |
| Relleno derecho del brazo superior |  | 01_Upper_Arm_Fuller_R.step | PLA Bambu Lab negro y verde | 1 | boquilla de 0.4 mm, altura de capa de 0.2 mm, relleno del 15% |
| Relleno central del brazo superior |  | 01_Upper_Arm_Fuller_M.step | ABS Bambu Lab negro | 1 | boquilla de 0.4 mm, altura de capa de 0.2 mm, relleno del 30% |
| Tope horizontal del brazo superior |  | 01_Upper_Arm_Limit.step | ABS Bambu Lab negro | 1 | boquilla de 0.4 mm, altura de capa de 0.2 mm, relleno del 30% |
| Asa del brazo |  | 01_Arm_Handle.step | ABS Bambu Lab negro | 1 | boquilla de 0.4 mm, altura de capa de 0.2 mm, relleno del 30% |
| Relleno izquierdo del brazo inferior |  | 01_Lower_Arm_Filler_L.step | PLA Bambu Lab negro y verde | 1 | boquilla de 0.4 mm, altura de capa de 0.2 mm, relleno del 15% |
| Relleno derecho del brazo inferior |  | 01_Lower_Arm_Filler_R.step | PLA Bambu Lab negro y verde | 1 | boquilla de 0.4 mm, altura de capa de 0.2 mm, relleno del 15% |
| Relleno central del brazo inferior |  | 01_Lower_Arm_Filler_M.step | ABS Bambu Lab negro | 1 | boquilla de 0.4 mm, altura de capa de 0.2 mm, relleno del 30% |
| Cubierta del brazo superior |  | 01_Upper_Arm_Cover.step | PLA Bambu Lab verde | 1 | boquilla de 0.4 mm, altura de capa de 0.2 mm, relleno del 15% |
| Cubierta del brazo inferior |  | 01_Lower_Arm_Cover.step | PLA Bambu Lab verde | 1 | boquilla de 0.4 mm, altura de capa de 0.2 mm, relleno del 15% |
| Cubierta de protección del motor 5 |  | 01_Motor_Cover.step | ABS Bambu Lab negro | 1 | boquilla de 0.4 mm, altura de capa de 0.2 mm, relleno del 30% |
| Tope horizontal de la pinza |  | 01_Lower_Arm_Limit.step | PLA Bambu Lab verde | 1 | boquilla de 0.4 mm, altura de capa de 0.2 mm, relleno del 15% |
| Soporte del carro de la pinza |  | 01-Rail-Bracket.step | PLA Bambu Lab verde | 1 | boquilla de 0.4 mm, altura de capa de 0.2 mm, relleno del 15% |
| Dedo de la pinza |  | 01_Finger.step | ABS Bambu Lab negro | 2 | boquilla de 0.4 mm, altura de capa de 0.2 mm, relleno del 45% |
| Sujeción de cables del motor 5 |  | 01_Joint5_Cable Restraint_A.step | PLA Bambu Lab verde | 1 | boquilla de 0.4 mm, altura de capa de 0.2 mm, relleno del 15% |
| Sujeción de cables A de los motores 6 y 7 |  | 01_Joint6_7_Cable Restraint_A.step | ABS Bambu Lab negro | 2 | boquilla de 0.4 mm, altura de capa de 0.2 mm, relleno del 30% |
| Sujeción de cables B de los motores 6 y 7 |  | 01_Joint6_7_Cable Restraint_B.step | ABS Bambu Lab negro | 2 | boquilla de 0.4 mm, altura de capa de 0.2 mm, relleno del 30% |
| - | Precio de referencia | Promedio **50 $** | | | El precio varía según el coste del material y el tiempo de impresión |

El roce continuado del arnés de cableado del motor 1 puede desgastar el conector del motor y provocar un mal contacto eléctrico. Imprimir las piezas que se indican a continuación puede mitigar este riesgo.

| Descripción de la pieza | Imagen | Nombre del archivo | Material | Cant. | Notas |
| ---- | ---- | ---- | ---- | ---- | ---- |
| Clips de arnés de cableado para ambos lados del motor 1 |  | `DM_Motor1_wiring_harness_clip.stp` | ABS Bambu Lab negro | 2 | boquilla de 0.4 mm, altura de capa de 0.2 mm, relleno del 30% |

## 📷 Soporte de cámara compatible

| Descripción de la pieza | Imagen | Nombre de archivo | Material | Cant. | Notas |
|---|---|---|---|---|---|
| [Orbbec Gemini2](https://www.seeedstudio.com/Orbbec-Gemini-2-3D-Camera-p-6464.html) |  | [`D435_Gemini2_Mount.step`](./3D_Printed_Parts/D435_Gemini2_Mount.step) | Bambu ABS Negro | 1 | Boquilla 0.4 mm, altura de capa 0.2 mm, relleno 30 % |

### 🧩 Recomendaciones de impresión
- Altura de capa: 0.2 mm
- Boquilla: 0.4 mm
- Soportes: añadir según sea necesario
- Materiales: las piezas sometidas a altas temperaturas y a carga se imprimen en ABS con un relleno del 30–80%; también pueden usarse nailon o materiales reforzados con fibra de carbono. Las piezas estéticas se imprimen en PLA con un relleno del 15%.
- Materiales recomendados para las piezas portantes: ABS con relleno del 30–80%, nailon o materiales reforzados con fibra de carbono

---

## 🔩 Piezas metálicas mecanizadas por CNC

> [!WARNING]
> Algunas piezas que pueden sustituirse por impresión 3D se indican en las notas, lo que puede reducir los costes considerablemente.

| Descripción de la pieza | Imagen | Nombre del archivo | Material | Cant. | Mecanizado | Notas |
|---|---|---|---|---|---|---|
| Soporte del rodamiento del motor 1 |  | 02_Base_Reinforcement_Part.step | Aleación de aluminio 5052 | 1 | CNC | Puede imprimirse en 3D en ABS con relleno alto para reducir el coste |
| Eje de rotación del motor 1 |  | 02_Arm_Yaw_Limit.step | Aleación de aluminio 5052 | 1 | CNC | Añade un límite de movimiento del ángulo de guiñada |
| Espaciador delantero de los motores 2–5 |  | 02_Motor_Front_Spacer.step | Aleación de aluminio 5052 | 4 | CNC | Puede imprimirse en 3D en ABS con relleno del 30% |
| Espaciador trasero de los motores 2–4 |  | 02_Motor_Back_Spacer.step | Aleación de aluminio 5052 | 3 | CNC | |
| Brida trasera de los motores 2–4 |  | 02_FLANGE.step | Aleación de aluminio 5052 | 3 | CNC | |
| Soporte del motor 5 de la muñeca |  | 02_Wrist_Bracket.step | Aleación de aluminio 5052 | 1 | CNC | |
| Conector A de la pinza |  | 02_Gripper_Connector_A.step | Aleación de aluminio 5052 | 1 | CNC | |
| Conector B de la pinza |  | 02_Gripper_Connector_B.step | Aleación de aluminio 5052 | 1 | CNC | |
| Soporte metálico del carro de la pinza |  | 02_Slider_Bracket.step | Aleación de aluminio 5052 | 1 | CNC | Puede imprimirse en 3D en ABS con relleno alto; no recomendado para uso prolongado |
| Extensión del carro a la pinza |  | 02_Slider_Extension.step | Aleación de aluminio 5052 | 2 | CNC | |
| Eslabón izquierdo entre brazo superior e inferior |  | 02_Lower_Upper_Link_L.step | Aleación de aluminio 5052 | 1 | CNC | |
| Eslabón derecho entre brazo superior e inferior |  | 02_Lower_Upper_Link_R.step | Aleación de aluminio 5052 | 1 | CNC | |
| Eslabón izquierdo entre brazo inferior y muñeca |  | 02_Lower_Wrist_Link_L.step | Aleación de aluminio 5052 | 1 | CNC | |
| Eslabón derecho entre brazo inferior y muñeca |  | 02_Lower_Wrist_Link_R.step | Aleación de aluminio 5052 | 1 | CNC | |
| Conector del engranaje |  | 02_Gear_Connector.step | Aleación de aluminio 5052 | 1 | CNC | |
| Cremallera |  | 02_Rack.step | Aleación de aluminio 5052 | 2 | CNC | |
| Eslabón 1 |  | 03_Link1.step | Aleación de aluminio 5052 | 1 | CNC + chapa metálica | |
| Eslabón 2 |  | 03_Link2.step | Aleación de aluminio 5052 | 2 | CNC + chapa metálica | |
| Eslabón 3 izquierdo |  | 03_Link3_L.step | Aleación de aluminio 5052 | 1 | CNC + chapa metálica | |
| Eslabón 3 derecho |  | 03_Link3_R.step | Aleación de aluminio 5052 | 1 | CNC + chapa metálica | |
| Eslabón 5 |  | 03_Link5.step | Aleación de aluminio 5052 | 1 | CNC + chapa metálica | |
| - | Precio de referencia de mercado | Promedio **250 $** | | | El precio varía según el coste del aluminio, los requisitos de tolerancia y el plazo de entrega |

### 🧩 Especificaciones de mecanizado
- Tolerancia de las cotas clave: ±0.02 mm GB/T1840-M
- Acabado superficial: anodizado / arenado
- Se recomienda usar H7 / ajuste por interferencia en las piezas de acoplamiento
---

## 🛒 Piezas compradas (piezas estándar)

> [!WARNING]
> Dado que cada uno tendrá que montar y apretar los tornillos por su cuenta, se han elegido tornillos Allen estándar. Tras un funcionamiento prolongado, los tornillos pueden aflojarse, lo que afectará a la precisión del brazo robótico. Por este motivo, debes comprar adicionalmente pegamento termofusible para fijar las roscas de los tornillos de cada articulación.

Si tienes un taladro eléctrico o herramientas similares, puedes optar por comprar arandelas de bloqueo o tornillos con freno de rosca. No obstante, **es sumamente importante** que uses el ajuste de par más bajo al utilizar un atornillador eléctrico para evitar que los tornillos se pasen de rosca, lo que provocaría daños irreversibles.

  | Nombre | Especificación / Modelo | Cantidad | Precio de referencia | Notas |
  |------|----------|------|----------|------|
  | Motor sin escobillas | DM4310(V4) | 4 | 120 $/unidad | [SeeedStudio](https://www.seeedstudio.com/Damiao-4310-Actuator-Motor-p-6823.html) |
  | Motor sin escobillas | DM4340P(V4) | 3 | 175 $/unidad |  [SeeedStudio](https://www.seeedstudio.com/DM4340P-Actuator-p-6663.html)  |
  | Placa driver CAN-USB |  | 1 | 15 $/unidad |   [SeeedStudio](https://www.seeedstudio.com/DM-CAN-USB-Driver-Borad-p-6706.html)   |
  | Rodamiento | 6707ZZ | 1 | 13 $/unidad | [Amazon](https://www.amazon.com/uxcell-35x44x5mm-Shielded-Precision-Lubricated/dp/B0D6WBMW3F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) |
  | Rodamiento | 6803ZZ | 3 | 13 $/unidad | [Amazon](https://www.amazon.com/uxcell-17x26x5mm-Shielded-Precision-Lubricated/dp/B0D54JSWBZ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) |
  | Rodamiento | AXK5578 | 1 | 12 $/unidad | [Amazon](https://www.amazon.com/PZRT-AXK5578-Thrust-Bearings-Washers/dp/B0B3M3RZGW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) |
  | Guía lineal | MGN9-170mm | 1 | 23 $/unidad | [Amazon](https://www.amazon.com/uxcell-Sliding-Carriage-Bearing-Printers/dp/B0D54L45WM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) |
  | Carro | MGN9 | 2 | 10 $/unidad | [Amazon](https://www.amazon.com/uxcell-Bearing-Sliding-Carriage-Anti-Fall/dp/B0D9QBQDKB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) |
  | Engranaje | Módulo 1, tipo cubo, 16 dientes, agujero de 6 mm | 1 | 44 $/unidad | [Amazon](https://www.amazon.com/Module-15-Teeth-Finished-Perforation/dp/B0GDSR1LKM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)  |
  | Almohadilla de silicona | 30x9x2mm | 1 | 10 $ | [Amazon](https://www.amazon.com/Self-Adhesive-Anti-Sliding-Anti-Scratch-Protectors-Appliances/dp/B0F9KVYXFZ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) |
  | Tornillo | Tornillo HM3-12mm | 14+ |  | [Amazon](https://www.amazon.com/BNUOK-120pcs-Stainless-Threads-Spanner/dp/B0DJQGMQZM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) |
  | Tornillo | Tornillo HM3-25mm | 14+ |  | [Amazon](https://www.amazon.com/BNUOK-120pcs-Stainless-Threads-Spanner/dp/B0DJQFGRPQ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)  |
  | Tornillo | Tornillo HM3-6mm | 16+ |  | [Amazon](https://www.amazon.com/BNUOK-120pcs-Stainless-Threads-Spanner/dp/B0DJQG5YLF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)  |
  | Tornillo | Tornillo prisionero HM4-75mm | 4+ |  | [Amazon](https://www.amazon.com/iexcell-Partially-Threaded-Thread-Socket/dp/B0DR1NX178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)  |
  | Tornillo | Tornillo KM3*12mm | 30+ |  |  [Amazon](https://www.amazon.com/Uxcell-a16011300ux0872-M3x12mm-Carbon-Countersunk/dp/B01E6EIC2S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) |
  | Tornillo | Tornillo KM3*16mm | 34+ |  | [Amazon](https://www.amazon.com/Uxcell-a16011300ux0872-M3x12mm-Carbon-Countersunk/dp/B01E6EIC2S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)  |
  | Tornillo | Tornillo KM3*7mm | 76+ |  |[Amazon](https://www.amazon.com/Uxcell-a16011300ux0872-M3x12mm-Carbon-Countersunk/dp/B01E6EIC2S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)   |
  | Tornillo | Tornillo KM3*9mm | 31+ |  |[Amazon](https://www.amazon.com/Uxcell-a16011300ux0872-M3x12mm-Carbon-Countersunk/dp/B01E6EIC2S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)   |
  | Tornillo | Tornillo KM3*8mm de cabeza baja con hueco hexagonal (Socket Micro Profile Head) | 31+ |  |[Amazon](https://www.amazon.com/SMALLRIG-Screw-Screws-12pcs-Pack/dp/B01MS60KSY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)   |
  | Tornillo | KA3*12mm | 72+ |  | [Amazon](https://www.amazon.com/uxcell-Phillips-Tapping-Screws-Silver/dp/B01MXSS95N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)  |
  | Pasador cilíndrico | M4*8mm | Varios |  | [Amazon](https://www.amazon.com/HARFINGTON-Stainless-Cylindrical-Furniture-Installation/dp/B0F6CWL4MP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)  |
  | Pasador cilíndrico | M4*12mm | Varios |  | [Amazon](https://www.amazon.com/HARFINGTON-Stainless-Cylindrical-Furniture-Installation/dp/B0F6CWL4MP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)  |
  | Juego de destornilladores | Juego de llaves hexagonales | 1 | 16 $  | [Amazon](https://www.amazon.com/Amazon-Basics-Ratcheting-Electronics-Screwdriver/dp/B07V4TFWFZ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)  |
  |  | XT30 2+2 350mm | 2 | 4 $/cable | Ambos extremos en ángulo |
  |  | XT30 2+2 350mm | 1 | 4 $/cable | Un extremo en ángulo y otro recto |
  |  | XT30 2+2 200mm | 3 | 4 $/cable | Ambos extremos en ángulo |
  |  | XT30 2+2 200mm | 1 | 3 $/cable | Ambos extremos rectos |

### Sobre la fijación
Puedes modificar libremente la base a partir de las piezas impresas en 3D que proporcionamos. También puedes usar sargentos en G según el grosor de tu mesa.

  | Nombre | Especificación / Modelo | Cantidad | Precio de referencia | Notas |
  |------|----------|------|----------|------|
  | Sargento de carpintería | Sargento en G de 6 pulgadas | 2 | 20 $/unidad | [Amazon](https://www.amazon.com/gp/aw/d/B092J1YW2M/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) |

### Sobre la alimentación
El brazo robótico se envía por defecto sin fuente de alimentación. Puedes conectar tu propia batería o comprar una fuente de alimentación MeanWell fiable de 24V 14.6A fabricada en Taiwán. Además, necesitarás comprar un enchufe de tres clavijas conforme a la normativa local y un arnés de cableado con conector XT30 hembra.

#### BOM de consumibles

| Nombre | Especificación | Cant. | Precio de referencia | Notas | Imagen |
|:---|:---|:---:|:---:|:---|:---:|
| Fuente de alimentación | LRS-350-24 (24V 14.6A) | 1 | 27.35 $ | [amazon](https://www.amazon.com/MEAN-WELL-LRS-350-24-350-4W-Switchable/dp/B013ETVO12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) |  |
| Cable de alimentación | Cable de CA estándar de EE. UU. | 1 | 4.49 $ | [amazon](https://www.amazon.com/LIFEPOE-Power-3-3ft-Black-3-Prong/dp/B0FK4KPW2G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) |  |
| Puerto de salida | Conector hembra fijo XT60E; XT60E hembra + terminal de ojal - 10cm; orificio del terminal de 4mm | 1 | 9.99 $ | [amazon](https://www.amazon.com/LINSYRC-XT60E-F-Connector-Battery-Quadcopter/dp/B0CQK1P1DP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) |  |
| Cableado de CA | 1.5mm²; rojo, azul y amarillo, 1 de cada (debes crimpar tú mismo los terminales al cable; no se incluyen cables precrimpados); 10CM | 3 | 0.99 $ | [aliexpress](https://www.aliexpress.com/item/1005008648016252.html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) |  |
| Base IEC 3 en 1 | Tipo de conexión rápida con interruptor rojo (doble tuerca) | 1 | 1.98 $ | [aliexpress](https://www.aliexpress.com/item/1005005962021242.html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) |  |
| Cable adaptador XT30 a XT60 | XT30U hembra a XT60 macho | 1 | 8.99 $ | [amazon](https://www.amazon.com/dp/B0BY8PSHK6?th=1) |  |
| Tornillo avellanado Phillips de acero inoxidable 304 | M4x6 | 6 | 0.37 $ | / | / |
| Tornillo avellanado Phillips de acero inoxidable 304 | M3x8 | 2 | 0.36 $ | / | / |
| Tornillo Phillips de cabeza alomada de acero inoxidable 304 | M3x8 | 2 | 0.32 $ | / | / |
| Tuerca hexagonal | M3x2.5 | 2 | ≈0.30 $ | / | / |

#### BOM de piezas impresas

| Nombre | Imagen | Cant. | Notas |
|:---|:---|:---:|:---|
| [Carcasa frontal](./3D_Printed_Parts/DM-power-Top%20Cover.stp) |  | 1 | PLA, boquilla de 0.4 mm, altura de capa de 0.2 mm, relleno del 30% |
| [Carcasa trasera](./3D_Printed_Parts/DM-power-Bottom%20Cover.stp) |  | 1 | PLA, boquilla de 0.4 mm, altura de capa de 0.2 mm, relleno del 30% |
| [Tapa deslizante de la carcasa frontal](./3D_Printed_Parts/DM-power-Top%20Cover-Sliding%20Cover.stp) |  | 1 | PLA, boquilla de 0.4 mm, altura de capa de 0.2 mm, relleno del 30% |

#### Montaje de la fuente de alimentación

El montaje de la fuente de alimentación se divide en dos secciones principales: la carcasa frontal y la carcasa trasera.

##### 1. Montaje de la carcasa frontal

| Paso | Instrucciones | Imagen | Notas |
|:---:|---|---|---|
| 1-1 | Prepara las piezas y los componentes impresos necesarios para el montaje de la carcasa frontal |  | Comprueba que todas las piezas estén completas |
| 1-2 | Consulta las indicaciones de la secuencia de cableado de cada pieza y monta siguiéndola | <br> | Sigue estrictamente la secuencia de cableado al conectar |
| 1-3 | Instala el conector XT60 |  | Fíjalo con tornillos avellanados Phillips de acero inoxidable 304 M3x8 y tuercas hexagonales M3x2.5 |
| 1-4 | Instala la base IEC 3 en 1 |  | Fija la base IEC 3 en 1 con tornillos Phillips de cabeza alomada de acero inoxidable 304 M3x8 |
| 1-5 | Cableado interno de la carcasa frontal | <br> | Comprueba las conexiones con el diagrama de la secuencia de cableado |
| 1-6 | Fija ambos lados de la carcasa frontal y la fuente de alimentación |  | Tornillos avellanados Phillips de acero inoxidable 304 M4x6 x2 |
| 1-7 | Instala la tapa deslizante |  | Introdúcela desde la parte inferior de la fuente de alimentación |
| 1-8 | Fija la tapa deslizante |  | Tornillos avellanados Phillips de acero inoxidable 304 M4x6 x2 |

---

##### 2. Montaje de la carcasa trasera

| Paso | Instrucciones | Imagen | Notas |
|:---:|---|---|---|
| 2-1 | Prepara las piezas y los componentes impresos necesarios para el montaje de la carcasa trasera |  | Comprueba que los accesorios estén completos |
| 2-2 | Monta la carcasa trasera con la fuente de alimentación |  | Alinea la posición |
| 2-3 | Fija ambos lados de la carcasa trasera y la fuente de alimentación |  | Tornillos avellanados Phillips de acero inoxidable 304 M4x6 x2 |

---

##### 3. Finalización del conjunto

| Paso | Instrucciones | Imagen | Notas |
|:---:|---|---|---|
| 1 | Montaje del sistema de alimentación completado |  | Comprueba que todos los tornillos estén apretados |

---

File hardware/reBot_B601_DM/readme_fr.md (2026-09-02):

# 🤖 Spécifications Matérielles Open Source du reBot DevArm

<p align="center">
  reBot-DevArm Banner
</p>
<p align="center">
  <strong>
    <a href="./readme_zh.md">简体中文</a> &nbsp;|&nbsp;
    <a href="./readme.md">English</a> &nbsp;|&nbsp;
    <a href="./readme_jp.md">日本語</a>&nbsp;|&nbsp;
    <a href="./readme_fr.md">français</a>&nbsp;|&nbsp;
    <a href="./readme_es.md">Español</a>
  </strong>
</p>

| Date | Version | Nom du fichier | Historique des modifications |
|---|---|---|---|
| 2026-03-31 | v1.0 | reBot_B601_DM_v1.0_20260331.step | Mise en ligne initiale |
| 2026-04-15 | v1.1 | reBot_B601_DM_v1.1_20260415.step | Ajout de colliers de câble pour les 3 moteurs d’articulation terminale afin d’éviter le desserrage et la déconnexion. Correction du modèle de l’articulation 1 de 4310 à 4340P. Ajout de la pièce usinée CNC 02_Base_Reinforcement_Part.step à la base pour renforcer la rigidité. |

Cette nomenclature (BOM) concerne le bras robotique reBot Arm B601 DM, équipé de moteurs Damiao série 43.
L’autre version, reBot Arm B601 RS, utilise des moteurs RobStride ; [voir la nomenclature ici](../reBot_B601_RS/README.md).

# 📦 Structure des fichiers
*   3D_Printed_Parts/ : Fichiers Step de toutes les pièces imprimées en 3D.
*   Metal_Parts/ : Fichiers Step de toutes les pièces métalliques usinées CNC.
*   Purchased_Parts/ : Fichiers Step de tous les composants standard achetés.
*   reBot_B601_DM_v1.1_20260415.step : Fichier d’assemblage complet du bras robotique.

# 🛒 [Obtenir toutes les pièces](https://www.seeedstudio.com/reBot-Arm-B601-DM-Bundle.html)
- Nous proposons cinq options de kit :
  - **Kit Moteurs du Bras** : Inclut uniquement les moteurs et faisceaux de câbles du bras robotique.
  - **Kit Structure du Bras** : Inclut uniquement les composants mécaniques de structure.
  - **Kit Complet Préhenseur** : Inclut moteurs, faisceaux de câbles et composants de structure du préhenseur.
  - **Kit Complet** : Inclut l’ensemble du corps du bras robotique et du préhenseur.
  - **Bras Robotique Pré-assemblé** : Bras robotique fini entièrement assemblé.

# 📊 Nomenclature (BOM)

> [!WARNING]
> Déclaration : La nomenclature publiée **ne représente pas** la version finale livrée par Seeed.
> Cette version open source v1.1 est optimisée pour que les développeurs puissent la reproduire à coût minimal, avec certains détails non essentiels simplifiés.
> La version de production finale Seeed comprendra une gravure laser métallique pour éviter les erreurs de montage, certaines pièces imprimées en 3D seront remplacées par du métal pour plus de durabilité, les jeux et tolérances d’usinage seront ajustés pour les variations industrielles (équilibre entre précision et coût), et un câblage personnalisé (avec gaine tressée par exemple) sera ajouté avec un coût supplémentaire. Cependant, la structure mécanique reste identique.

---

## 🖨️ Pièces imprimées en 3D

| Description de la pièce | Image | Nom du fichier | Matériau | Qté | Notes |
|---|---|---|---|---|---|
| Plaque de base du bras robotique |  | 01_BASE_Plate.step | Bambu ABS Noir | 1 | Buse 0.4, hauteur de couche 0.2, remplissage 30% |
| Liaison de base du bras robotique |  | 01_BASE_Link.step | Bambu ABS Noir | 1 | Buse 0.4, hauteur de couche 0.2, remplissage 30% |
| Garniture côté gauche du bras supérieur |  | 01_Upper_Arm_Fuller_L.step | Bambu PLA Noir & Vert | 1 | Buse 0.4, hauteur de couche 0.2, remplissage 15% |
| Garniture côté droit du bras supérieur |  | 01_Upper_Arm_Fuller_R.step | Bambu PLA Noir & Vert | 1 | Buse 0.4, hauteur de couche 0.2, remplissage 15% |
| Garniture centrale du bras supérieur |  | 01_Upper_Arm_Fuller_M.step | Bambu ABS Noir | 1 | Buse 0.4, hauteur de couche 0.2, remplissage 30% |
| Butée de limite horizontale du bras supérieur |  | 01_Upper_Arm_Limit.step | Bambu ABS Noir | 1 | Buse 0.4, hauteur de couche 0.2, remplissage 30% |
| Poignée du bras |  | 01_Arm_Handle.step | Bambu ABS Noir | 1 | Buse 0.4, hauteur de couche 0.2, remplissage 30% |
| Garniture côté gauche du bras inférieur |  | 01_Lower_Arm_Filler_L.step | Bambu PLA Noir & Vert | 1 | Buse 0.4, hauteur de couche 0.2, remplissage 15% |
| Garniture côté droit du bras inférieur |  | 01_Lower_Arm_Filler_R.step | Bambu PLA Noir & Vert | 1 | Buse 0.4, hauteur de couche 0.2, remplissage 15% |
| Garniture centrale du bras inférieur |  | 01_Lower_Arm_Filler_M.step | Bambu ABS Noir | 1 | Buse 0.4, hauteur de couche 0.2, remplissage 30% |
| Cache du bras supérieur |  | 01_Upper_Arm_Cover.step | Bambu PLA Vert | 1 | Buse 0.4, hauteur de couche 0.2, remplissage 15% |
| Cache du bras inférieur |  | 01_Lower_Arm_Cover.step | Bambu PLA Vert | 1 | Buse 0.4, hauteur de couche 0.2, remplissage 15% |
| Cache de protection du moteur 5 |  | 01_Motor_Cover.step | Bambu ABS Noir | 1 | Buse 0.4, hauteur de couche 0.2, remplissage 30% |
| Butée de limite horizontale du préhenseur |  | 01_Lower_Arm_Limit.step | Bambu PLA Vert | 1 | Buse 0.4, hauteur de couche 0.2, remplissage 15% |
| Support de coulisseau du préhenseur |  | 01-Rail-Bracket.step | Bambu PLA Vert | 1 | Buse 0.4, hauteur de couche 0.2, remplissage 15% |
| Doigt de préhenseur |  | 01_Finger.step | Bambu ABS Noir | 2 | Buse 0.4, hauteur de couche 0.2, remplissage 45% |
| Collier de câble du moteur 5 |  | 01_Joint5_Cable Restraint_A.step | Bambu PLA Vert | 1 | Buse 0.4, hauteur de couche 0.2, remplissage 15% |
| Collier de câble A pour moteurs 6 & 7 |  | 01_Joint6_7_Cable Restraint_A.step | Bambu ABS Noir | 2 | Buse 0.4, hauteur de couche 0.2, remplissage 30% |
| Collier de câble B pour moteurs 6 & 7 |  | 01_Joint6_7_Cable Restraint_B.step | Bambu ABS Noir | 2 | Buse 0.4, hauteur de couche 0.2, remplissage 30% |
| - | Prix de référence | Moyenne **50$** | | | Prix variable selon coût du matériau et temps d’impression |

Lors d’une utilisation prolongée, le tirage répété du faisceau de câbles 1 provoque l’usure du connecteur du moteur et entraîne des défauts de contact. Imprimez les pièces listées ci-dessous pour limiter ce risque.

| Désignation de la pièce | Image | Nom du fichier | Matériau | Quantité | Remarques |
| ---- | ---- | ---- | ---- | ---- | ---- |
| Attache de faisceau pour les deux faces du moteur 1 |  | `DM_Motor1_wiring_harness_clip.stp` | ABS noir Bambu Lab | 2 | Buse 0,4 mm, hauteur de couche 0,2 mm, remplissage 30 % |

## 📷 Support de caméra compatible

| Description de la pièce | Image | Nom du fichier | Matériau | Qté | Notes |
|---|---|---|---|---|---|
| [Orbbec Gemini2](https://www.seeedstudio.com/Orbbec-Gemini-2-3D-Camera-p-6464.html) |  | [`D435_Gemini2_Mount.step`](./3D_Printed_Parts/D435_Gemini2_Mount.step) | Bambu ABS Noir | 1 | Buse 0.4, hauteur de couche 0.2, remplissage 30% |

### 🧩 Recommandations d’impression
- Hauteur de couche : 0.2 mm
- Buse : 0.4 mm
- Supports : Ajouter si nécessaire
- Matériaux : Pièces résistant à la chaleur et aux charges : ABS avec remplissage 30–80% ; nylon ou matériaux renforcés de fibre de carbone également possibles. Pièces esthétiques : PLA avec remplissage 15%.
- Matériaux recommandés pour les pièces sous charge :

---

## 🔩 Pièces métalliques usinées CNC

> [!WARNING]
> Certaines pièces pouvant être remplacées par impression 3D sont indiquées en note, ce qui permet de réduire significativement les coûts.

| Description de la pièce | Image | Nom du fichier | Matériau | Qté | Usinage | Notes |
|---|---|---|---|---|---|---|
| Support de palier du moteur 1 |  | 02_Base_Reinforcement_Part.step | Alliage d’aluminium 5052 | 1 | CNC | Peut être imprimé en 3D en ABS avec fort remplissage pour réduire les coûts |
| Axe de rotation du moteur 1 avec butée |  | 02_Arm_Yaw_Limit.step | Alliage d’aluminium 5052 | 1 | CNC | Ajout de limite de mouvement en lacet |
| Entretoise avant moteurs 2–5 |  | 02_Motor_Front_Spacer.step | Alliage d’aluminium 5052 | 4 | CNC | Peut être imprimé en 3D en ABS avec remplissage 30% |
| Entretoise arrière moteurs 2–4 |  | 02_Motor_Back_Spacer.step | Alliage d’aluminium 5052 | 3 | CNC | |
| Bride arrière moteurs 2–4 |  | 02_FLANGE.step | Alliage d’aluminium 5052 | 3 | CNC | |
| Support du moteur poignet 5 |  | 02_Wrist_Bracket.step | Alliage d’aluminium 5052 | 1 | CNC | |
| Raccord préhenseur A |  | 02_Gripper_Connector_A.step | Alliage d’aluminium 5052 | 1 | CNC | |
| Raccord préhenseur B |  | 02_Gripper_Connector_B.step | Alliage d’aluminium 5052 | 1 | CNC | |
| Support métallique de coulisseau préhenseur |  | 02_Slider_Bracket.step | Alliage d’aluminium 5052 | 1 | CNC | Peut être imprimé en 3D en ABS avec fort remplissage, non recommandé pour une utilisation prolongée |
| Extension coulisseau-préhenseur |  | 02_Slider_Extension.step | Alliage d’aluminium 5052 | 2 | CNC | |
| Liaison gauche bras supérieur-bras inférieur |  | 02_Lower_Upper_Link_L.step | Alliage d’aluminium 5052 | 1 | CNC | |
| Liaison droite bras supérieur-bras inférieur |  | 02_Lower_Upper_Link_R.step | Alliage d’aluminium 5052 | 1 | CNC | |
| Liaison gauche bras inférieur-poignet |  | 02_Lower_Wrist_Link_L.step | Alliage d’aluminium 5052 | 1 | CNC | |
| Liaison droite bras inférieur-poignet |  | 02_Lower_Wrist_Link_R.step | Alliage d’aluminium 5052 | 1 | CNC | |
| Raccord de pignon |  | 02_Gear_Connector.step | Alliage d’aluminium 5052 | 1 | CNC | |
| Rack |  | 02_Rack.step | Alliage d’aluminium 5052 | 2 | CNC | |
| Liaison 1 |  | 03_Link1.step | Alliage d’aluminium 5052 | 1 | CNC + tôlerie | |
| Liaison 2 |  | 03_Link2.step | Alliage d’aluminium 5052 | 2 | CNC + tôlerie | |
| Liaison 3 gauche |  | 03_Link3_L.step | Alliage d’aluminium 5052 | 1 | CNC + tôlerie | |
| Liaison 3 droite |  | 03_Link3_R.step | Alliage d’aluminium 5052 | 1 | CNC + tôlerie | |
| Liaison 5 |  | 03_Link5.step | Alliage d’aluminium 5052 | 1 | CNC + tôlerie | |
| - | Prix de référence marché | Moyenne **250$** | | | Prix variable selon coût de l’aluminium, exigences de tolérance, délais |

### 🧩 Spécifications d’usinage
- Tolérance dimensionnelle clé : ±0.02 mm GB/T1840-M
- Finition de surface : Anodisation / sablage
- Pièces d’assemblage recommandées : ajustement H7 / ajustement serré

---

## 🛒 Pièces achetées (pièces standard)

> [!WARNING]
> Comme chacun devra assembler et serrer les vis soi-même, des vis hexagonales intérieures standard ont été sélectionnées. Après un fonctionnement prolongé, les vis peuvent se desserrer, ce qui affecte la précision du bras robotique. Pour cette raison, vous devez acheter en plus de la colle chaude pour effectuer un freinage fileté sur les vis de chaque articulation.

Si vous disposez d’une perceuse électrique ou d’outils similaires, vous pouvez choisir d’acheter des rondelles freins ou des vis freins filetées à la place. Cependant, **il est extrêmement important** d’utiliser le réglage de couple le plus bas avec un tournevis électrique pour éviter d’arracher les filets, ce qui entraînerait des dommages irréversibles.

| Nom | Spécification / Modèle | Quantité | Prix de référence | Notes |
|---|---|---|---|---|
| Moteur sans balais | DM4310(V4) | 4 | 120 $/unité | [SeeedStudio](https://www.seeedstudio.com/Damiao-4310-Actuator-Motor-p-6823.html) |
| Moteur sans balais | DM4340P(V4) | 3 | 175 $/unité | [SeeedStudio](https://www.seeedstudio.com/DM4340P-Actuator-p-6663.html) |
| Carte d’interface CAN-USB | - | 1 | 15 $/unité | [SeeedStudio](https://www.seeedstudio.com/DM-CAN-USB-Driver-Borad-p-6706.html) |
| Palier | 6707ZZ | 1 | 13 $/unité | [Amazon](https://www.amazon.com/uxcell-35x44x5mm-Shielded-Precision-Lubricated/dp/B0D6WBMW3F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) |
| Palier | 6803ZZ | 3 | 13 $/unité | [Amazon](https://www.amazon.com/uxcell-17x26x5mm-Shielded-Precision-Lubricated/dp/B0D54JSWBZ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) |
| Palier | AXK5578 | 1 | 12 $/unité | [Amazon](https://www.amazon.com/PZRT-AXK5578-Thrust-Bearings-Washers/dp/B0B3M3RZGW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) |
| Rail linéaire | MGN9-170mm | 1 | 23 $/unité | [Amazon](https://www.amazon.com/uxcell-Sliding-Carriage-Bearing-Printers/dp/B0D54L45WM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) |
| Bloc coulissant | MGN9 | 2 | 10 $/unité | [Amazon](https://www.amazon.com/uxcell-Bearing-Sliding-Carriage-Anti-Fall/dp/B0D9QBQDKB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) |
| Pignon | Module 1, type moyeu, 16 dents, alésage 6 mm | 1 | 44 $/unité | [Amazon](https://www.amazon.com/Module-15-Teeth-Finished-Perforation/dp/B0GDSR1LKM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) |
| Patin en silicone | 30x9x2mm | 1 | 10 $ | [Amazon](https://www.amazon.com/Self-Adhesive-Anti-Sliding-Anti-Scratch-Protectors-Appliances/dp/B0F9KVYXFZ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) |
| Vis | HM3-12mm | 14+ | - | [Amazon](https://www.amazon.com/BNUOK-120pcs-Stainless-Threads-Spanner/dp/B0DJQGMQZM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) |
| Vis | HM3-25mm | 14+ | - | [Amazon](https://www.amazon.com/BNUOK-120pcs-Stainless-Threads-Spanner/dp/B0DJQFGRPQ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) |
| Vis | HM3-6mm | 16+ | - | [Amazon](https://www.amazon.com/BNUOK-120pcs-Stainless-Threads-Spanner/dp/B0DJQG5YLF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) |
| Vis | HM4-75mm sans tête | 4+ | - | [Amazon](https://www.amazon.com/iexcell-Partially-Threaded-Thread-Socket/dp/B0DR1NX178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) |
| Vis | KM3×12mm fraisée | 30+ | - | [Amazon](https://www.amazon.com/Uxcell-a16011300ux0872-M3x12mm-Carbon-Countersunk/dp/B01E6EIC2S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) |
| Vis | KM3×16mm fraisée | 34+ | - | [Amazon](https://www.amazon.com/Uxcell-a16011300ux0872-M3x12mm-Carbon-Countersunk/dp/B01E6EIC2S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) |
| Vis | KM3×7mm fraisée | 76+ | - | [Amazon](https://www.amazon.com/Uxcell-a16011300ux0872-M3x12mm-Carbon-Countersunk/dp/B01E6EIC2S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) |
| Vis | KM3×9mm fraisée | 31+ | - | [Amazon](https://www.amazon.com/Uxcell-a16011300ux0872-M3x12mm-Carbon-Countersunk/dp/B01E6EIC2S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) |
| Vis | KM3×8mm fraisée à tête très basse | 31+ | - | [Amazon](https://www.amazon.com/SMALLRIG-Screw-Screws-12pcs-Pack/dp/B01MS60KSY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) |
| Vis | KA3×12mm tête bombée | 72+ | - | [Amazon](https://www.amazon.com/uxcell-Phillips-Tapping-Screws-Silver/dp/B01MXSS95N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) |
| Goupille cylindrique | M4×8mm | Plusieurs | - | [Amazon](https://www.amazon.com/HARFINGTON-Stainless-Cylindrical-Furniture-Installation/dp/B0F6CWL4MP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) |
| Goupille cylindrique | M4×12mm | Plusieurs | - | [Amazon](https://www.amazon.com/HARFINGTON-Stainless-Cylindrical-Furniture-Installation/dp/B0F6CWL4MP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) |
| Jeu de tournevis | Jeu de clés hexagonales | 1 | 16 $ | [Amazon](https://www.amazon.com/Amazon-Basics-Ratcheting-Electronics-Screwdriver/dp/B07V4TFWFZ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) |
|  | XT30 2+2 350mm | 2 | 4 $/câble | Deux extrémités coudées |
|  | XT30 2+2 350mm | 1 | 4 $/câble | Une extrémité coudée, une droite |
|  | XT30 2+2 200mm | 3 | 4 $/câble | Deux extrémités coudées |
|  | XT30 2+2 200mm | 1 | 3 $/câble | Deux extrémités droites |

### Concernant la fixation
Vous pouvez modifier librement la base à l'aide des pièces imprimées en 3D fournies. Vous pouvez également utiliser des serre-joints en fonction de l'épaisseur de votre plateau de table.

| Désignation | Spécifications / Référence | Quantité | Prix de référence | Remarques |
|---|---|---|---|---|
| Serre-joint à bois | Serre-joint G de 6 pouces | 2 | 20 $/unité | [Amazon](https://www.amazon.com/gp/aw/d/B092J1YW2M/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) |

### Concernant l'alimentation électrique
Le bras robotique est livré sans alimentation d'origine. Vous pouvez brancher votre propre batterie ou acheter une alimentation fiable MeanWell de 24V 14,6A fabriquée à Taïwan. De plus, vous devrez vous procurer une fiche trois broches conforme aux normes locales ainsi qu'un faisceau de câbles équipé d'un connecteur femelle XT30.

#### Nomenclature des consommables

| Désignation | Spécifications | Qté | Prix de référence | Remarques | Image |
|:---|:---|:---:|:---:|:---|:---:|
| Alimentation | LRS-350-24 (24V 14,6A) | 1 | 27,35 $ | [amazon](https://www.amazon.com/MEAN-WELL-LRS-350-24-350-4W-Switchable/dp/B013ETVO12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) |  |
| Cordon d'alimentation | Câble secteur standard US | 1 | 4,49 $ | [amazon](https://www.amazon.com/LIFEPOE-Power-3-3ft-Black-3-Prong/dp/B0FK4KPW2G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) |  |
| Port de sortie | Connecteur femelle fixe XT60E ; XT60E femelle + cosse - 10 cm ; trou de cosse 4 mm | 1 | 9,99 $ | [amazon](https://www.amazon.com/LINSYRC-XT60E-F-Connector-Battery-Quadcopter/dp/B0CQK1P1DP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) |  |
| Câblage secteur | 1,5 mm² ; rouge, bleu, jaune, 1 de chaque (l'utilisateur doit sertir lui-même les cosses sur les fils — cordons pré-sertis non fournis) ; 10 cm | 3 | 0,99 $ | [aliexpress](https://www.aliexpress.com/item/1005008648016252.html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) |  |
| Prise IEC 3-en-1 | Type à connexion rapide avec interrupteur rouge (double écrou) | 1 | 1,98 $ | [aliexpress](https://www.aliexpress.com/item/1005005962021242.html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) |  |
| Câble adaptateur XT30 vers XT60 | XT30U femelle vers XT60 mâle | 1 | 8,99 $ | [amazon](https://www.amazon.com/dp/B0BY8PSHK6?th=1) |  |
| Vis à tête fraisée cruciforme inox 304 | M4x6 | 6 | 0,37 $ | / | / |
| Vis à tête fraisée cruciforme inox 304 | M3x8 | 2 | 0,36 $ | / | / |
| Vis à tête bombée cruciforme inox 304 | M3x8 | 2 | 0,32 $ | / | / |
| Écrou hexagonal | M3x2,5 | 2 | 2,10 CNY | / | / |

#### Nomenclature des pièces imprimées

| Désignation | Image | Qté | Notes |
|:---|:---|:---:|:---|
| [Capot avant](./3D_Printed_Parts/DM-power-Top%20Cover.stp) |  | 1 | PLA, buse 0,4 mm, hauteur de couche 0,2 mm, remplissage 30 % |
| [Capot arrière](./3D_Printed_Parts/DM-power-Bottom%20Cover.stp) |  | 1 | PLA, buse 0,4 mm, hauteur de couche 0,2 mm, remplissage 30 % |
| [Capot avant coulissant](./3D_Printed_Parts/DM-power-Top%20Cover-Sliding%20Cover.stp) |  | 1 | PLA, buse 0,4 mm, hauteur de couche 0,2 mm, remplissage 30 % |

#### Assemblage de l'alimentation

L'assemblage de l'alimentation se divise en deux parties principales : le capot avant et le capot arrière.

##### 1. Assemblage du capot avant

| Étape | Instructions | Image | Remarques |
|:---:|---|---|---|
| 1-1 | Préparer les pièces et les pièces imprimées nécessaires à l'assemblage du capot avant |  | Vérifier que toutes les pièces sont présentes |
| 1-2 | Explication de l'ordre de câblage de chaque pièce ; assembler en respectant cet ordre | <br> | Raccorder strictement selon l'ordre de câblage |
| 1-3 | Installer le connecteur XT60 |  | Fixer avec des vis à tête fraisée cruciforme inox 304 M3x8 et des écrous hexagonaux M3x2,5 |
| 1-4 | Installer la prise IEC 3-en-1 |  | Fixer la prise IEC 3-en-1 avec des vis à tête bombée cruciforme inox 304 M3x8 |
| 1-5 | Câblage interne du capot avant | <br> | Vérifier les raccordements à l'aide du schéma d'ordre de câblage |
| 1-6 | Fixer les deux côtés du capot avant et l'alimentation |  | Vis à tête fraisée cruciforme inox 304 M4x6 x2 |
| 1-7 | Installer le capot coulissant |  | Insérer par le dessous de l'alimentation |
| 1-8 | Fixer le capot coulissant |  | Vis à tête fraisée cruciforme inox 304 M4x6 x2 |

---

##### 2. Assemblage du capot arrière

| Étape | Instructions | Image | Remarques |
|:---:|---|---|---|
| 2-1 | Préparer les pièces et les pièces imprimées nécessaires à l'assemblage du capot arrière |  | Vérifier que les accessoires sont complets |
| 2-2 | Assembler le capot arrière avec l'alimentation |  | Aligner la position |
| 2-3 | Fixer les deux côtés du capot arrière et l'alimentation |  | Vis à tête fraisée cruciforme inox 304 M4x6 x2 |

---

##### 3. Assemblage terminé

| Étape | Instructions | Image | Remarques |
|:---:|---|---|---|
| 1 | Assemblage de la solution d'alimentation terminé |  | Vérifier que toutes les vis sont serrées |

---

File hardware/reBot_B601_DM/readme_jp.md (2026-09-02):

# 🤖 reBot DevArm オープンソースハードウェア仕様書

<p align="center">
  reBot-DevArm バナー
</p>
<p align="center">
  <strong>
    <a href="./readme_zh.md">简体中文</a> &nbsp;|&nbsp;
    <a href="./readme.md">English</a> &nbsp;|&nbsp;
    <a href="./readme_jp.md">日本語</a>&nbsp;|&nbsp;
    <a href="./readme_fr.md">français</a>&nbsp;|&nbsp;
    <a href="./readme_es.md">Español</a>
  </strong>
</p>

| 日付 | バージョン | ファイル名 | 変更履歴 |
|---|---|---|---|
| 2026-03-31 | v1.0 | reBot_B601_DM_v1.0_20260331.step | 初回アップロード |
| 2026-04-15 | v1.1 | reBot_B601_DM_v1.1_20260415.step | エンドジョイント3つのモーターにケーブル拘束を追加し、緩みや外れを防止。ジョイント1のモデルを4310から4340Pに修正。ベース剛性を高めるため、底部にCNCパーツ 02_Base_Reinforcement_Part.step を追加。 |

このBOMは、大疆43シリーズモーターを使用する reBot Arm B601 DM ロボットアーム用です。もう一方のバージョンである reBot Arm B601 RS は RobStride モーターを使用しています。[BOMはこちら](../reBot_B601_RS/README.md)をご覧ください。

# 📦 ファイル構成
*   3D_Printed_Parts/: すべての3Dプリント部品のStepファイル。
*   Metal_Parts/: すべてのCNC加工金属部品のStepファイル。
*   Purchased_Parts/: すべての購入部品のStepファイル。
*   reBot_B601_DM_v1.1_20260415.step: ロボットアームのフルアセンブリファイル。

# 🛒[全部品を入手](https://www.seeedstudio.com/reBot-Arm-B601-DM-Bundle.html)
- 5種類のキットオプションを提供しています：
  - **アームボディモーターキット**: ロボットアーム用のモーターと配線ハーネスのみを含む。
  - **アームボディ構造キット**: 機械的構造部品のみを含む。
  - **グリッパーコンプリートキット**: グリッパー用のモーター、配線ハーネス、構造部品を含む。
  - **フルキット**: ロボットアーム本体とグリッパーの完全なセットを含む。
  - **組立済みロボットアーム**: 完全に組み立てられた完成品のロボットアーム。

# 📊 部品表 (BOM)

> [!WARNING]
> 宣言: 公開されているBOMは、Seeedからの最終出荷バージョンを**示すものではありません**。このオープンソースv1.1は、開発者が最小コストで再現できるように最適化されており、一部の必須でない詳細は簡略化されています。
> Seeedの最終生産バージョンには、誤動作防止のための金属レーザー刻印、耐久性のために一部の3Dプリント部品を金属に置き換え、工場でのばらつきに対応するためのクリアランスと加工公差の調整（精度とコストのバランス）、および追加コストでのカスタム配線（例：組み紐スリーブ保護）が含まれます。ただし、機械的構造は同一です。

---

## 🖨️ 3Dプリント部品

| 部品説明 | 画像 | ファイル名 | 材料 | 数量 | 注記 |
|---|---|---|---|---|---|
| ロボットアームベースプラットフォーム |  | 01_BASE_Plate.step | Bambu ABS Black | 1 | 0.4mmノズル、0.2mmレイヤー高さ、30%インフィル |
| ロボットアームベースリンク |  | 01_BASE_Link.step | Bambu ABS Black | 1 | 0.4mmノズル、0.2mmレイヤー高さ、30%インフィル |
| 上アーム左フィラー |  | 01_Upper_Arm_Fuller_L.step | Bambu PLA Black & Green | 1 | 0.4mmノズル、0.2mmレイヤー高さ、15%インフィル |
| 上アーム右フィラー |  | 01_Upper_Arm_Fuller_R.step | Bambu PLA Black & Green | 1 | 0.4mmノズル、0.2mmレイヤー高さ、15%インフィル |
| 上アーム中央フィラー |  | 01_Upper_Arm_Fuller_M.step | Bambu ABS Black | 1 | 0.4mmノズル、0.2mmレイヤー高さ、30%インフィル |
| 上アーム水平リミットブロック |  | 01_Upper_Arm_Limit.step | Bambu ABS Black | 1 | 0.4mmノズル、0.2mmレイヤー高さ、30%インフィル |
| アームハンドル |  | 01_Arm_Handle.step | Bambu ABS Black | 1 | 0.4mmノズル、0.2mmレイヤー高さ、30%インフィル |
| 下アーム左フィラー |  | 01_Lower_Arm_Filler_L.step | Bambu PLA Black & Green | 1 | 0.4mmノズル、0.2mmレイヤー高さ、15%インフィル |
| 下アーム右フィラー |  | 01_Lower_Arm_Filler_R.step | Bambu PLA Black & Green | 1 | 0.4mmノズル、0.2mmレイヤー高さ、15%インフィル |
| 下アーム中央フィラー |  | 01_Lower_Arm_Filler_M.step | Bambu ABS Black | 1 | 0.4mmノズル、0.2mmレイヤー高さ、30%インフィル |
| 上アームカバー |  | 01_Upper_Arm_Cover.step | Bambu PLA Green | 1 | 0.4mmノズル、0.2mmレイヤー高さ、15%インフィル |
| 下アームカバー |  | 01_Lower_Arm_Cover.step | Bambu PLA Green | 1 | 0.4mmノズル、0.2mmレイヤー高さ、15%インフィル |
| モーター5保護カバー |  | 01_Motor_Cover.step | Bambu ABS Black | 1 | 0.4mmノズル、0.2mmレイヤー高さ、30%インフィル |
| グリッパー水平リミット |  | 01_Lower_Arm_Limit.step | Bambu PLA Green | 1 | 0.4mmノズル、0.2mmレイヤー高さ、15%インフィル |
| グリッパースライダーサポートブラケット |  | 01-Rail-Bracket.step | Bambu PLA Green | 1 | 0.4mmノズル、0.2mmレイヤー高さ、15%インフィル |
| グリッパーフィンガー |  | 01_Finger.step | Bambu ABS Black | 2 | 0.4mmノズル、0.2mmレイヤー高さ、45%インフィル |
| モーター5 ケーブル拘束 |  | 01_Joint5_Cable Restraint_A.step | Bambu PLA Green | 1 | 0.4mmノズル、0.2mmレイヤー高さ、15%インフィル |
| モーター6＆7 ケーブル拘束 A |  | 01_Joint6_7_Cable Restraint_A.step | Bambu ABS Black | 2 | 0.4mmノズル、0.2mmレイヤー高さ、30%インフィル |
| モーター6＆7 ケーブル拘束 B |  | 01_Joint6_7_Cable Restraint_B.step | Bambu ABS Black | 2 | 0.4mmノズル、0.2mmレイヤー高さ、30%インフィル |
| - | 参考価格 | 平均 **50$** | | | 材料費と印刷時間により価格変動 |

配線ハーネス1を長期間引き回して使用すると、モーター側コネクタが摩耗し、接触不良が発生する可能性があります。
下記の部品を3Dプリンタで造形することで、この不具合リスクを抑えられます。

| 部品詳細 | 画像 | ファイル名 | 材質 | 個数 | 備考 |
| ---- | ---- | ---- | ---- | ---- | ---- |
| 1号モーター両面用配線ハーネスクリップ |  | `DM_Motor1_wiring_harness_clip.stp` | Bambu Lab 黒ABS樹脂 | 2個 | ノズル径0.4mm、積層ピッチ0.2mm、充填率30% |

## 📷 対応カメラマウント

| 部品説明 | 画像 | ファイル名 | 材料 | 数量 | 注記 |
|---|---|---|---|---|---|
| [Orbbec Gemini2](https://www.seeedstudio.com/Orbbec-Gemini-2-3D-Camera-p-6464.html) |  | [`D435_Gemini2_Mount.step`](./3D_Printed_Parts/D435_Gemini2_Mount.step) | Bambu ABS Black | 1 | 0.4mmノズル、0.2mmレイヤー高さ、30%インフィル |

### 🧩 印刷推奨事項
- レイヤー高さ: 0.2 mm
- ノズル: 0.4 mm
- サポート: 必要に応じて追加
- 材料: 高温・耐荷重部品にはABS（インフィル30～80%）、ナイロンまたはカーボン繊維強化材料も可。外装部品にはPLA（インフィル15%）。
- 耐荷重部品の推奨材料：

---

## 🔩 CNC加工金属部品

> [!WARNING]
> 注記に記載されている一部の部品は3Dプリントに置き換え可能で、コストを大幅に削減できます。

| 部品説明 | 画像 | ファイル名 | 材料 | 数量 | 加工 | 注記 |
|---|---|---|---|---|---|---|
| モーター1 ベアリングマウント |  | 02_Base_Reinforcement_Part.step | アルミニウム合金 5052 | 1 | CNC | コスト削減のため、高インフィルABSで3Dプリント可能 |
| モーター1 回転軸 |  | 02_Arm_Yaw_Limit.step | アルミニウム合金 5052 | 1 | CNC | ヨー角運動制限を追加 |
| モーター2–5 フロントスペーサー |  | 02_Motor_Front_Spacer.step | アルミニウム合金 5052 | 4 | CNC | ABS、インフィル30%で3Dプリント可能 |
| モーター2–4 リアスペーサー |  | 02_Motor_Back_Spacer.step | アルミニウム合金 5052 | 3 | CNC | |
| モーター2–4 リアフランジ |  | 02_FLANGE.step | アルミニウム合金 5052 | 3 | CNC | |
| 手首モーター5 ブラケット |  | 02_Wrist_Bracket.step | アルミニウム合金 5052 | 1 | CNC | |
| グリッパーコネクタ A |  | 02_Gripper_Connector_A.step | アルミニウム合金 5052 | 1 | CNC | |
| グリッパーコネクタ B |  | 02_Gripper_Connector_B.step | アルミニウム合金 5052 | 1 | CNC | |
| グリッパースライダー金属ブラケット |  | 02_Slider_Bracket.step | アルミニウム合金 5052 | 1 | CNC | 高インフィルABSで3Dプリント可能だが、長期使用は非推奨 |
| スライダーからグリッパーへの延長部 |  | 02_Slider_Extension.step | アルミニウム合金 5052 | 2 | CNC | |
| 上下アームリンク左 |  | 02_Lower_Upper_Link_L.step | アルミニウム合金 5052 | 1 | CNC | |
| 上下アームリンク右 |  | 02_Lower_Upper_Link_R.step | アルミニウム合金 5052 | 1 | CNC | |
| 下アーム-手首リンク左 |  | 02_Lower_Wrist_Link_L.step | アルミニウム合金 5052 | 1 | CNC | |
| 下アーム-手首リンク右 |  | 02_Lower_Wrist_Link_R.step | アルミニウム合金 5052 | 1 | CNC | |
| ギアコネクタ |  | 02_Gear_Connector.step | アルミニウム合金 5052 | 1 | CNC | |
| ラック |  | 02_Rack.step | アルミニウム合金 5052 | 2 | CNC | |
| リンク 1 |  | 03_Link1.step | アルミニウム合金 5052 | 1 | CNC + 板金 | |
| リンク 2 |  | 03_Link2.step | アルミニウム合金 5052 | 2 | CNC + 板金 | |
| リンク 3 左 |  | 03_Link3_L.step | アルミニウム合金 5052 | 1 | CNC + 板金 | |
| リンク 3 右 |  | 03_Link3_R.step | アルミニウム合金 5052 | 1 | CNC + 板金 | |
| リンク 5 |  | 03_Link5.step | アルミニウム合金 5052 | 1 | CNC + 板金 | |
| - | 市場参考価格 | 平均 **250$** | | | アルミニウムコスト、公差要件、納期により価格変動 |

### 🧩 加工仕様
- 主要寸法公差: ±0.02 mm GB/T1840-M
- 表面仕上げ: アルマイト / サンドブラスト
- 嵌合部品推奨: H7 / インターフェリンスフィット
---

## 🛒 購入部品 (標準部品)

> [!WARNING]
> 組み立て・ネジ締めはご自身で行っていただく必要があるため、標準的な六角穴付きネジを選択しています。長時間の動作後、ネジが緩み、ロボットアームの精度に影響を与える可能性があります。そのため、各ジョイントのネジにネジロックを行うためのホットメルト接着剤を別途購入する必要があります。

電動ドリルなどの工具をお持ちの場合は、代わりにロックワッシャーやネジロック剤付きネジを購入しても構いません。ただし、電動ドライバーを使用する際は**非常に重要なこと**ですが、ネジ山をなめないように最も低いトルク設定を使用してください。ネジ山をなめると、元に戻せない損傷が発生します。

| 名前 | 仕様 / モデル | 数量 | 参考価格 | 注記 |
|---|---|---|---|---|
| ブラシレスモーター | DM4310(V4) | 4 | 120 $/unit | [SeeedStudio](https://www.seeedstudio.com/Damiao-4310-Actuator-Motor-p-6823.html) |
| ブラシレスモーター | DM4340P(V4) | 3 | 175 $/unit | [SeeedStudio](https://www.seeedstudio.com/DM4340P-Actuator-p-6663.html) |
| CAN-USBドライバーボード | | 1 | 15 $/unit | [SeeedStudio](https://www.seeedstudio.com/DM-CAN-USB-Driver-Borad-p-6706.html) |
| ベアリング | 6707ZZ | 1 | 13 $/unit | [Amazon](https://www.amazon.com/uxcell-35x44x5mm-Shielded-Precision-Lubricated/dp/B0D6WBMW3F/ref=sr_1_1) |
| ベアリング | 6803ZZ | 3 | 13 $/unit | [Amazon](https://www.amazon.com/uxcell-17x26x5mm-Shielded-Precision-Lubricated/dp/B0D54JSWBZ/ref=sr_1_1) |
| ベアリング | AXK5578 | 1 | 12 $/unit | [Amazon](https://www.amazon.com/PZRT-AXK5578-Thrust-Bearings-Washers/dp/B0B3M3RZGW/ref=sr_1_1) |
| リニアレール | MGN9-170mm | 1 | 23 $/unit | [Amazon](https://www.amazon.com/uxcell-Sliding-Carriage-Bearing-Printers/dp/B0D54L45WM/ref=sr_1_1) |
| スライダーブロック | MGN9 | 2 | 10 $/unit | [Amazon](https://www.amazon.com/uxcell-Bearing-Sliding-Carriage-Anti-Fall/dp/B0D9QBQDKB/ref=sr_1_8) |
| ギア | モジュール1、ボス型、16歯、ボア6mm | 1 | 44$/unit | [Amazon](https://www.amazon.com/Module-15-Teeth-Finished-Perforation/dp/B0GDSR1LKM/ref=sr_1_1) |
| シリコンパッド | 30x9x2mm | 1 | 10 $ | [Amazon](https://www.amazon.com/Self-Adhesive-Anti-Sliding-Anti-Scratch-Protectors-Appliances/dp/B0F9KVYXFZ/ref=sr_1_3) |
| ネジ | HM3-12mm ネジ | 14+ | | [Amazon](https://www.amazon.com/BNUOK-120pcs-Stainless-Threads-Spanner/dp/B0DJQGMQZM/ref=sr_1_4) |
| ネジ | HM3-25mm ネジ | 14+ | | [Amazon](https://www.amazon.com/BNUOK-120pcs-Stainless-Threads-Spanner/dp/B0DJQFGRPQ/ref=sr_1_4) |
| ネジ | HM3-6mm ネジ | 16+ | | [Amazon](https://www.amazon.com/BNUOK-120pcs-Stainless-Threads-Spanner/dp/B0DJQG5YLF/ref=sr_1_4) |
| ネジ | HM4-75mm 止めネジ | 4+ | | [Amazon](https://www.amazon.com/iexcell-Partially-Threaded-Thread-Socket/dp/B0DR1NX178/ref=sr_1_1) |
| ネジ | KM3*12mm ネジ | 30+ | | [Amazon](https://www.amazon.com/Uxcell-a16011300ux0872-M3x12mm-Carbon-Countersunk/dp/B01E6EIC2S/ref=sr_1_1) |
| ネジ | KM3*16mm ネジ | 34+ | | [Amazon](https://www.amazon.com/Uxcell-a16011300ux0872-M3x12mm-Carbon-Countersunk/dp/B01E6EIC2S/ref=sr_1_1) |
| ネジ | KM3*7mm ネジ | 76+ | | [Amazon](https://www.amazon.com/Uxcell-a16011300ux0872-M3x12mm-Carbon-Countersunk/dp/B01E6EIC2S/ref=sr_1_1) |
| ネジ | KM3*9mm ネジ | 31+ | | [Amazon](https://www.amazon.com/Uxcell-a16011300ux0872-M3x12mm-Carbon-Countersunk/dp/B01E6EIC2S/ref=sr_1_1) |
| ネジ | KM3*8mm マイクロプロファイル六角穴付きネジ | 31+ | | [Amazon](https://www.amazon.com/SMALLRIG-Screw-Screws-12pcs-Pack/dp/B01MS60KSY/ref=sr_1_1) |
| ネジ | KA3*12mm | 72+ | | [Amazon](https://www.amazon.com/uxcell-Phillips-Tapping-Screws-Silver/dp/B01MXSS95N/ref=sr_1_3) |
| 位置決めピン | M4*8mm | 数本 | | [Amazon](https://www.amazon.com/HARFINGTON-Stainless-Cylindrical-Furniture-Installation/dp/B0F6CWL4MP/ref=sr_1_6) |
| 位置決めピン | M4*12mm | 数本 | | [Amazon](https://www.amazon.com/HARFINGTON-Stainless-Cylindrical-Furniture-Installation/dp/B0F6CWL4MP/ref=sr_1_6) |
| ドライバーセット | 六角レンチセット | 1 | 16$ | [Amazon](https://www.amazon.com/Amazon-Basics-Ratcheting-Electronics-Screwdriver/dp/B07V4TFWFZ/ref=sr_1_2) |
|  | XT30 2+2 350mm | 2 | 4 $/cable | 両端アングル |
|  | XT30 2+2 350mm | 1 | 4 $/cable | 一端アングル、一端ストレート |
|  | XT30 2+2 200mm | 3 | 4 $/cable | 両端アングル |
|  | XT30 2+2 200mm | 1 | 3 $/cable | 両端ストレート |

### 固定方法について
付属の3Dプリント部品を基に、土台を自由に加工していただけます。机の天板の厚さに合わせて、Gクランプを使用することも可能です。

| 名称 | 仕様/型式 | 数量 | 参考価格 | 備考 |
|---|---|---|---|---|
| 木工用クランプ | 6インチ Gクランプ | 2個 | 1個あたり20ドル | [Amazon](https://www.amazon.com/gp/aw/d/B092J1YW2M/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) |

### 電源について
本ロボットアームは標準で電源が付属しておりません。お手持ちのバッテリーを接続するか、台湾製の信頼性の高い**24V 14.6A MeanWell製電源**を別途ご購入ください。
加えて、現地基準に適合した3ピンプラグ、及びXT30メスコネクタ付き配線ハーネスもご用意いただく必要があります。

#### 消耗品BOM

| 名称 | 仕様 | 数量 | 参考価格 | 備考 | 画像 |
|:---|:---|:---:|:---:|:---|:---:|
| 電源装置 | LRS-350-24 (24V 14.6A) | 1 | 27.35ドル | [amazon](https://www.amazon.com/MEAN-WELL-LRS-350-24-350-4W-Switchable/dp/B013ETVO12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) |  |
| 電源コード | 米国規格ACケーブル | 1 | 4.49ドル | [amazon](https://www.amazon.com/LIFEPOE-Power-3-3ft-Black-3-Prong/dp/B0FK4KPW2G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) |  |
| 出力ポート | XT60E 固定メスコネクタ／XT60E メス＋圧着端子 - 10cm／端子穴 4mm | 1 | 9.99ドル | [amazon](https://www.amazon.com/LINSYRC-XT60E-F-Connector-Battery-Quadcopter/dp/B0CQK1P1DP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) |  |
| AC電源配線 | 1.5mm²、赤・青・黄 各1本（端子はご自身で圧着してください。圧着済みリード線は付属しません）、10cm | 3 | 0.99ドル | [aliexpress](https://www.aliexpress.com/item/1005008648016252.html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) |  |
| 三合一 IEC インレットソケット | 赤色スイッチ付きクイックコネクトタイプ（ダブルナット） | 1 | 1.98ドル | [aliexpress](https://www.aliexpress.com/item/1005005962021242.html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) |  |
| XT30-XT60 変換ケーブル | XT30U メス - XT60 オス | 1 | 8.99ドル | [amazon](https://www.amazon.com/dp/B0BY8PSHK6?th=1) |  |
| 304ステンレス 十字穴付き皿ねじ | M4x6 | 6 | 0.37ドル | / | / |
| 304ステンレス 十字穴付き皿ねじ | M3x8 | 2 | 0.36ドル | / | / |
| 304ステンレス 十字穴付きなべねじ | M3x8 | 2 | 0.32ドル | / | / |
| 六角ナット | M3x2.5 | 2 | 2.10 CNY | / | / |

#### プリント部品BOM

| 名称 | 画像 | 数量 | 備考 |
|:---|:---|:---:|:---|
| [フロントカバー](./3D_Printed_Parts/DM-power-Top%20Cover.stp) |  | 1 | PLA、0.4mmノズル、0.2mmレイヤー高さ、30%インフィル |
| [リアカバー](./3D_Printed_Parts/DM-power-Bottom%20Cover.stp) |  | 1 | PLA、0.4mmノズル、0.2mmレイヤー高さ、30%インフィル |
| [フロントカバー スライドカバー](./3D_Printed_Parts/DM-power-Top%20Cover-Sliding%20Cover.stp) |  | 1 | PLA、0.4mmノズル、0.2mmレイヤー高さ、30%インフィル |

#### 電源の組み立て

電源の組み立ては、フロントカバーとリアカバーの二つの工程に分かれます。

##### 1. フロントカバーの組み立て

| Step | 操作手順 | 画像 | 備考 |
|:---:|---|---|---|
| 1-1 | フロントカバーの組み立てに必要な部品とプリント部品を準備する |  | 部品がすべて揃っているか確認してください |
| 1-2 | 各部品の結線順序の説明。結線順序に従って組み立てる | <br> | 必ず結線順序どおりに接続してください |
| 1-3 | XT60 コネクタを取り付ける |  | 304ステンレス十字穴付き皿ねじ M3x8 と六角ナット M3x2.5 で固定します |
| 1-4 | 三合一 IEC ソケットを取り付ける |  | 三合一 IEC ソケットを304ステンレス十字穴付きなべねじ M3x8 で固定します |
| 1-5 | フロントカバー内部の配線 | <br> | 結線順序図と照らし合わせて接続を確認してください |
| 1-6 | フロントカバーと電源の両側を固定する |  | 304ステンレス十字穴付き皿ねじ M4x6 ×2 |
| 1-7 | スライドカバーを取り付ける |  | 電源の下側から差し込みます |
| 1-8 | スライドカバーを固定する |  | 304ステンレス十字穴付き皿ねじ M4x6 ×2 |

---

##### 2. リアカバーの組み立て

| Step | 操作手順 | 画像 | 備考 |
|:---:|---|---|---|
| 2-1 | リアカバーの組み立てに必要な部品とプリント部品を準備する |  | 付属品がすべて揃っているか確認してください |
| 2-2 | リアカバーと電源を組み合わせる |  | 位置を合わせてください |
| 2-3 | リアカバーと電源の両側を固定する |  | 304ステンレス十字穴付き皿ねじ M4x6 ×2 |

---

##### 3. 組み立て完了

| Step | 操作手順 | 画像 | 備考 |
|:---:|---|---|---|
| 1 | 電源ソリューションの組み立てが完了しました |  | すべてのねじが締まっているか確認してください |

---

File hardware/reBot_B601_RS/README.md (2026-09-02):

# 🤖 reBot DevArm Open Source Hardware Specification

<p align="center">
  reBot-DevArm Banner
</p>
<p align="center">
  <strong>
    <a href="./README_zh.md">简体中文</a> &nbsp;|&nbsp;
    <a href="./README.md">English</a> &nbsp;|&nbsp;
    <a href="./README_fr.md">français</a>&nbsp;|&nbsp;
    <a href="./README_es.md">Español</a>
  </strong>
</p>

| Date | Version | File Name | Changelog |
|---|---|---|---|
|  2026-07-09 | v1.0 |  reBot_B601_RS_v1.0_20260625.step  | Initial upload |

This BOM is for the reBot Arm B601 RS robotic arm, which uses ROBOSTRIDE series motors. The other version, reBot Arm B601 DM, uses DAMIAO motors; [see the BOM here](../reBot_B601_DM/readme.md).

# 📦 File Structure
*   3D_Printed_Parts/: Step files for all 3D printed parts.
*   Metal_Parts/: Step files for all CNC machined metal parts.
*   Purchased_Parts/: Step files for all purchased components.
*   reBot_B601_RS_v1.0_20260625.step: Full robotic arm assembly file.

# 🛒[Gets All Parts](https://www.seeedstudio.com/reBot-Arm-B601-RS-Disassembly-Kit-Version-with-Power-Supply-Bundle.html)
- We offer five kit options:
  - **reBot-Arm-B601-RS-Disassembly-Kit**
  - **reBot-Arm-B601-RS-Assembly-Version**

# 📊 Bill of Materials (BOM)

> [!WARNING]
> Declaration: The published BOM does **not** represent the final shipping version from Seeed. This open-source v1.0 is optimized for developers to reproduce at minimal cost, with some non-essential details simplified.
> The final Seeed production version will include metal laser engraving for foolproofing, some 3D printed parts will be replaced with metal for durability, clearances and machining tolerances will be adjusted for factory variation (balancing precision and cost), and custom wiring (e.g., braided sleeve protection) will be added at extra cost. However, the mechanical structure remains identical.

---

## 🖨️ 3D Printed Parts

| Part Description | Image | File Name | Material | Qty | Notes |
|---|---|---|---|---|---|
| Robotic Arm Base Platform |  | 1-BASE-PLATE.step | Bambu ABS Black | 1 | 0.4 nozzle, 0.2 layer height, 30% infill |
| Robotic Arm Base Link |  | 1-RSM1-STATOR-1.step | Bambu ABS Black | 1 | 0.4 nozzle, 0.2 layer height, 30% infill |
| Upper Arm Left Filler |  | 1-DOWN-DL.step | Bambu PLA Black & Green | 1 | 0.4 nozzle, 0.2 layer height, 15% infill |
| Upper Arm Right Filler |  | 1-DOWN-DR.step | Bambu PLA Black & Green | 1 | 0.4 nozzle, 0.2 layer height, 15% infill |
| Upper Arm and Lower Arm Center Filler |  | 1-SPACE-UP.step | Bambu ABS Black | 2 | 0.4 nozzle, 0.2 layer height, 30% infill |
| Arm Handle |  | 1-HANDLE.step | Bambu ABS Black | 1 | 0.4 nozzle, 0.2 layer height, 30% infill |
| Upper and Lower Arm Cover |  | 1-COVER.step | Bambu PLA Green | 2 | 0.4 nozzle, 0.2 layer height, 15% infill |
| Lower Arm Left Filler |  | 1-UP-DL.step | Bambu PLA Black & Green | 1 | 0.4 nozzle, 0.2 layer height, 15% infill |
| Lower Arm Right Filler |  | 1-UP-DR.step | Bambu PLA Black & Green | 1 | 0.4 nozzle, 0.2 layer height, 15% infill |
| Gripper Horizontal Limit |  | 1-STOPPER-1.step | Bambu PLA Green | 1 | 0.4 nozzle, 0.2 layer height, 15% infill |
| Gripper Slider Support Bracket |  | 1-RAIL-BASE-2.step | Bambu PLA Green | 1 | 0.4 nozzle, 0.2 layer height, 15% infill |
| Gripper Finger |  | 1-CLIP.step | Bambu ABS Black | 2 | 0.4 nozzle, 0.2 layer height, 45% infill. Print from the side of the gripper to improve its structural strength. |

Long-term dragging of Wiring Harness 1 may abrade the motor connector and result in poor electrical contact. Printing the parts listed below can mitigate this risk.

| Part Description | Image | File Name | Material | Qty | Remarks |
| ---- | ---- | ---- | ---- | ---- | ---- |
| Wiring Harness Clips for Two Sides of Motor 1 |  | `RS_Motor1_wiring_harness_clip.stp` | Bambu Lab Black ABS | 2 | 0.4 mm nozzle, 0.2 mm layer height, 30% infill |

### 🧩 Printing Recommendations
- Layer height: 0.2 mm
- Nozzle: 0.4 mm
- Supports: Add as needed
- Materials: High-temperature and load-bearing parts use ABS with 30–80% infill; may also use nylon or carbon-fiber reinforced materials. Cosmetic parts use PLA with 15% infill.
- Recommended materials for load-bearing parts:

---

## 🔩 CNC Machined Metal Parts

> [!WARNING]
> Some parts that can be replaced with 3D printing are noted in the remarks, which can significantly reduce costs.

| Part Description | Image | File Name | Material | Qty | Machining | Notes |
|---|---|---|---|---|---|---|
| Motor 1 Bearing Mount |  | 2-RSM1-ROTOR-1.step | Aluminum Alloy 5052 | 1 | CNC |  |
| Link1 Left Metal |  | 2-RSM-ROTOR-L.step | Aluminum Alloy 5052 | 1 | CNC |  |
| Link1 Right Metal |  | 2-RSM-ROTOR-R.step | Aluminum Alloy 5052 | 4 | CNC ||
| Link1 Bottom Metal |  | 2-RSM1-ROTOR-1.step | Aluminum Alloy 5052 | 3 | CNC | |
| Joint Metal Disc  |  | 2-CD.step | Aluminum Alloy 5052 | 3 | CNC | Used to Conceal Screws |
| RS06 Front Extesnion |  | 2-RSM2-STATOR-1.step | Aluminum Alloy 5052 | 2 | CNC | |
| RS06 Back Extesnion |  | 2-RSM2-STATOR-2.step | Aluminum Alloy 5052 | 2 | CNC | |
| Link2 Left and Right Metal |  | 2-LINK-2_3.step | Aluminum Alloy 5052 | 2 | CNC | |
| Upper Limit L |  | 2-Upper-Limit_L.stp | Aluminum Alloy 5052 | 1 | CNC | |
| Upper Limit R |  | 2-Upper-Limit_R.stp | Aluminum Alloy 5052 | 1 | CNC | |
| Lower & Upper Link L|  | 2-RSM3-ROTATOR-L.step | Aluminum Alloy 5052 | 1 | CNC | |
| Lower & Upper Link R|  | 2-RSM3-ROTATOR-R.step | Aluminum Alloy 5052 | 1 | CNC | |
| Link3 Left Metal|  | 2-LINK-3_4-L.step | Aluminum Alloy 5052 | 1 | CNC | |
| Link3 Right Metal|  | 2-LINK-3_4-R.step | Aluminum Alloy 5052 | 1 | CNC | |
| Link3 Right & Left Link |  | 2-SPACE-UP-2.step | Aluminum Alloy 5052 | 1 | CNC | |
| Motor4-7 Cable Fixing |  | 1-O-CLIP.step | Aluminum Alloy 5052 | 4 | CNC | Seeedstudio ships this part as a single CNC-machined metal component integrated with another part, which drives up manufacturing costs. If you reproduce the hardware on your own, you can 3D-print this part with ABS material and install M2 nuts at the positions marked by red arrows. |
| Motor4 Back Cable |  | 2-Motor_Back_Spacer.step | Aluminum Alloy 5052 | 1 | CNC |  |
| Link4-5_L |  | 2-LINK-4_5-L.step | Aluminum Alloy 5052 | 1 | CNC | |
| Link4-5_R |  | 2-LINK-4_5-R.step | Aluminum Alloy 5052 | 1 | CNC | |
| Link5 |  | 2-RSM5-STATOR.step | Aluminum Alloy 5052 | 1 | CNC | |
|Wrist_Connector_A |  | 2-RSM6-RORATOR-1.step | Aluminum Alloy 5052 | 1 | CNC |  |
|Wrist_Connector_B |  | 2-RSM6-RORATOR-2.step | Aluminum Alloy 5052 | 1 | CNC |  |
| Gripper Connector A |  | 2-M6-ROTOR.step  | Aluminum Alloy 5052 | 1 | CNC | |
| Gripper Connector B |  | 2-M7-STATOR.step  | Aluminum Alloy 5052 | 1 | CNC | |
| Gripper Slider Metal Bracket |  | 2-RAIL-BASE-1.step | Aluminum Alloy 5052 | 1 | CNC | Can be 3D printed in ABS with high infill, not recommended for long-term use |
| Slider to Gripper Extension |  | 2-SLIDER-FIX.step | Aluminum Alloy 5052 | 2 | CNC | |
| Rack |  | 2-RACK-1M.step | Aluminum Alloy 5052 | 2 | CNC | |

### 🧩 Machining Specifications
- Key dimension tolerance: ±0.02 mm GB/T1840-M
- Surface finish: Anodizing / Sandblasting
- Mating parts recommended: H7 / interference fit
---

## 🛒 Purchased Parts (Standard Parts)

> [!WARNING]
> Since everyone will need to assemble and tighten the screws themselves, standard hex socket screws have been selected. After prolonged operation, the screws may loosen, which will affect the precision of the robotic arm. For this reason, you are required to purchase additional hot melt glue to perform thread locking on the screws at each joint.

If you have a power drill or similar tools, you may choose to buy lock washers or thread-locking screws instead. However, **it is extremely important** that you use the lowest torque setting when using an electric screwdriver to avoid thread stripping, which will result in irreversible damage.

  | Name | Specification / Model | Quantity | Reference Price | Notes |
  |------|----------|------|----------|------|
  | Brushless motor | RobStride RS00 | 4 | 125 $/unit | [SeeedStudio](https://www.seeedstudio.com/Robostride-00-Actuator-p-6664.html) |
  | Brushless motor | RobStride RS06 | 3 | 210 $/unit |  [SeeedStudio](https://www.seeedstudio.com/Robostride-06-Actuator-p-6668.html)  |
  | CAN-USB driver board |  | 1 | 15 $/unit |   [SeeedStudio](https://www.amazon.com/Xiusiyt-Converter-Preloaded-PCAN-Firmware/dp/B0GBW7RTXD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)   |
  | XT30 2+2 Power Separation Borrd |  | 1 | 15 $/unit |   [SeeedStudio](https://www.seeedstudio.com/XT30-2-2-Power-Separation-Board-p-6707.html)   |
  | Bearing | 6803ZZ | 3 | 13 $/unit | [Amazong](https://www.amazon.com/uxcell-17x26x5mm-Shielded-Precision-Lubricated/dp/B0D54JSWBZ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) |
  | Bearing | AXK5578 | 1 | 12 $/unit | [Amazong](https://www.amazon.com/PZRT-AXK5578-Thrust-Bearings-Washers/dp/B0B3M3RZGW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) |
  | Linear rail | MGN9-170mm | 1 | 23 $/unit | [Amazong](https://www.amazon.com/uxcell-Sliding-Carriage-Bearing-Printers/dp/B0D54L45WM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) |
  | Slider block | MGN9 | 2 | 10 $/unit | [Amazong](https://www.amazon.com/uxcell-Bearing-Sliding-Carriage-Anti-Fall/dp/B0D9QBQDKB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) |
  | Gear | Module 1, boss type, 16 teeth, 6 mm bore | 1 | 44$/unit | [Amazong](https://www.amazon.com/Module-15-Teeth-Finished-Perforation/dp/B0GDSR1LKM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)  |
  | Silicone pad | 30x9x2mm | 1 | 10 $ | [Amazong](https://www.amazon.com/Self-Adhesive-Anti-Sliding-Anti-Scratch-Protectors-Appliances/dp/B0F9KVYXFZ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) |
  | Screw | KM3*7mm screw | 80+ |  |[Amazong](https://www.amazon.com/Uxcell-a16011300ux0872-M3x12mm-Carbon-Countersunk/dp/B01E6EIC2S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)   |
  | Screw | KM3*16mm screw | 8+ |  |[Amazong](https://www.amazon.com/Uxcell-a16011300ux0872-M3x12mm-Carbon-Countersunk/dp/B01E6EIC2S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)   |
  | Screw | KA3*12mm | 48+ |  | [Amazong](https://www.amazon.com/uxcell-Phillips-Tapping-Screws-Silver/dp/B01MXSS95N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)  |
  | Screw | HM3-8mm screw | 60+ |  | [Amazong](https://www.amazon.com/BNUOK-120pcs-Stainless-Threads-Spanner/dp/B0DJQG5YLF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)  |
  | Screw | HM3-30mm screw | 16+ |  | [Amazong](https://www.amazon.com/BNUOK-120pcs-Stainless-Threads-Spanner/dp/B0DJQFGRPQ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) 
  | Screw | HM4-8mm set screw | 6+ |  | [Amazong](https://www.amazon.com/iexcell-Partially-Threaded-Thread-Socket/dp/B0DR1NX178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)  |
  | Screw | HM4-16mm set screw | 18+ |  | [Amazong](https://www.amazon.com/iexcell-Partially-Threaded-Thread-Socket/dp/B0DR1NX178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)  |
  | Screw | HM4-70mm set screw | 4+ |  | [Amazong](https://www.amazon.com/iexcell-Partially-Threaded-Thread-Socket/dp/B0DR1NX178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)  |
 | Screw | HM3-6mm screw | 8+ |  | [Amazong](https://www.amazon.com/BNUOK-120pcs-Stainless-Threads-Spanner/dp/B0DJQG5YLF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)  |
 | Screw | HM3-26mm screw | 6+ |  | [Amazong](https://www.amazon.com/BNUOK-120pcs-Stainless-Threads-Spanner/dp/B0DJQG5YLF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)  |
 | XT30 2+2 Cable | Two Side Elbows 320mm | 1+ |   | This will require custom fabrication on your end.  |
 | XT30 2+2 Cable | Two Side Elbows 200mm | 4+ |   | This will require custom fabrication on your end.  |
 | XT30 2+2 Cable | One Side Elbow 300mm| 1+ |   |  This will require custom fabrication on your end. |
 | XT30 2+2 Cable | Two Side Straight | 1+ |  |   |
  | Screwdriver set | Hex key set | 1 | 16$  | [Amazong](https://www.amazon.com/Amazon-Basics-Ratcheting-Electronics-Screwdriver/dp/B07V4TFWFZ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)  |

### About Fixing
You may modify your base freely based on the 3D printed parts we provide. You can also use G-clamps according to the thickness of your desktop.

  | Name | Specification / Model | Quantity | Reference Price | Notes |
  |------|----------|------|----------|------|
  | Woodworking clamp | 6-inch G clamp | 2 | 20 $/unit | [Amazong](https://www.amazon.com/gp/aw/d/B092J1YW2M/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) |

### About Power Supply
The robotic arm is shipped without a power supply by default. You may connect your own battery, or purchase a reliable 48V 12.5A MeanWell power supply made in Taiwan. Additionally, you will need to buy a three-pin plug compliant with local standards and a wiring harness with XT30 female connector.
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

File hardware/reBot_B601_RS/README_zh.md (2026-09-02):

# 🤖 reBot DevArm 开源硬件规格说明

<p align="center">
  reBot-DevArm Banner
</p>
<p align="center">
  <strong>
    <a href="./README_zh.md">简体中文</a> &nbsp;|&nbsp;
    <a href="./README.md">English</a> &nbsp;|&nbsp;
    <a href="./README_fr.md">français</a>&nbsp;|&nbsp;
    <a href="./README_es.md">Español</a>
  </strong>
</p>

| 日期 | 版本 | 文件名 | 更新记录 |
| --- | ---- | --- | ---- |
| 2026-07-09 | v1.0 | reBot_B601_RS_v1.0_20260625.step | 首次上传 |

本 BOM 适用于 reBot Arm B601 RS 机械臂，该版本使用 ROBOSTRIDE 系列电机。另一个版本 reBot Arm B601 DM 使用 DAMIAO 电机；[请在此查看 BOM](../reBot_B601_DM/readme.md)。

# 📦 文件结构

* `3D_Printed_Parts/`：所有 3D 打印部件的 STEP 文件。
* `Metal_Parts/`：所有 CNC 加工金属部件的 STEP 文件。
* `Purchased_Parts/`：所有采购标准件的 STEP 文件。
* `reBot_B601_RS_v1.0_20260625.step`：完整机械臂装配文件。

# 🛒[获取所有零件](https://www.seeedstudio.com/reBot-Arm-B601-RS-Disassembly-Kit-Version-with-Power-Supply-Bundle.html)

* 我们提供五种套件选项：

  * **reBot-Arm-B601-RS-Disassembly-Kit**
  * **reBot-Arm-B601-RS-Assembly-Version**

# 📊 物料清单（BOM）

> [!WARNING]
> 声明：本次公开的 BOM **并不代表** Seeed 最终出货版本。本开源 v1.0 版本面向开发者以较低成本复现为目标，因此简化了一些非必要细节。
>
> Seeed 最终量产版本将包含用于防呆的金属激光雕刻；部分 3D 打印件会替换为金属件以提升耐用性；配合间隙和加工公差会根据工厂批量生产差异进行调整，以平衡精度和成本；同时还会增加定制线束，例如编织网保护等额外成本项。不过，机械结构本身保持一致。

---

## 🖨️ 3D 打印部件

| 部件描述 | 图片 | 文件名 | 材料 | 数量 | 备注 |
| --- | --- | --- | --- | -- | --- |
| 机械臂底座平台 |  | 1-BASE-PLATE.step | Bambu ABS 黑色 | 1  | 0.4 喷嘴，0.2 层高，30% 填充 |
| 机械臂底座连杆 |  | 1-RSM1-STATOR-1.step | Bambu ABS 黑色 | 1  | 0.4 喷嘴，0.2 层高，30% 填充 |
| 上臂左侧填充件 |  | 1-DOWN-DL.step | Bambu PLA 黑色与绿色 | 1  | 0.4 喷嘴，0.2 层高，15% 填充 |
| 上臂右侧填充件 |  | 1-DOWN-DR.step | Bambu PLA 黑色与绿色 | 1  | 0.4 喷嘴，0.2 层高，15% 填充 |
| 上臂与下臂中间填充件 |  | 1-SPACE-UP.step | Bambu ABS 黑色 | 2  | 0.4 喷嘴，0.2 层高，30% 填充 |
| 机械臂提手 |  | 1-HANDLE.step | Bambu ABS 黑色 | 1  | 0.4 喷嘴，0.2 层高，30% 填充 |
| 上臂与下臂盖板 |  | 1-COVER.step | Bambu PLA 绿色 | 2  | 0.4 喷嘴，0.2 层高，15% 填充 |
| 下臂左侧填充件 |  | 1-UP-DL.step | Bambu PLA 黑色与绿色 | 1  | 0.4 喷嘴，0.2 层高，15% 填充 |
| 下臂右侧填充件 |  | 1-UP-DR.step | Bambu PLA 黑色与绿色 | 1  | 0.4 喷嘴，0.2 层高，15% 填充 |
| 夹爪水平限位件 |  | 1-STOPPER-1.step | Bambu PLA 绿色 | 1  | 0.4 喷嘴，0.2 层高，15% 填充 |
| 夹爪滑轨支撑支架 |  | 1-RAIL-BASE-2.step | Bambu PLA 绿色 | 1  | 0.4 喷嘴，0.2 层高，15% 填充 |
| 夹爪手指 |  | 1-CLIP.step | Bambu ABS 黑色 | 2  | 0.4 喷嘴，0.2 层高，45% 填充。建议从夹爪侧面方向打印，以提升结构强度。 |

长时间拖拽线束 1 可能会磨损电机连接器，并导致电气接触不良。打印下表中的部件可以降低该风险。

| 部件描述 | 图片 | 文件名 | 材料 | 数量 | 备注 |
| --- | --- | --- | --- | -- | --- |
| 电机 1 两侧线束固定夹 |  | `RS_Motor1_wiring_harness_clip.stp` | Bambu Lab 黑色 ABS | 2  | 0.4 mm 喷嘴，0.2 mm 层高，30% 填充 |

### 🧩 打印建议

* 层高：0.2 mm
* 喷嘴：0.4 mm
* 支撑：根据需要添加
* 材料：高温和承重部件建议使用 ABS，填充率 30–80%；也可以使用尼龙或碳纤维增强材料。外观件建议使用 PLA，填充率 15%。
* 承重部件推荐材料：

---

## 🔩 CNC 加工金属部件

> [!WARNING]
> 部分可由 3D 打印替代的部件已在备注中说明，这可以显著降低成本。

| 部件描述 | 图片 | 文件名 | 材料 | 数量 | 加工方式 | 备注 |
| --- | --- | --- | --- | -- | ---- | --- |
| 电机 1 轴承安装座 |  | 2-RSM1-ROTOR-1.step | 5052 铝合金 | 1  | CNC  | |
| Link1 左侧金属件  |  | 2-RSM-ROTOR-L.step | 5052 铝合金 | 1  | CNC  | |
| Link1 右侧金属件  |  | 2-RSM-ROTOR-R.step | 5052 铝合金 | 4  | CNC  | |
| Link1 底部金属件  |  | 2-RSM1-ROTOR-1.step | 5052 铝合金 | 3  | CNC  | |
| 关节金属圆盘 |  | 2-CD.step | 5052 铝合金 | 3  | CNC  | 用于遮挡螺丝 |
| RS06 前侧延长件 |  | 2-RSM2-STATOR-1.step  | 5052 铝合金 | 2  | CNC  | |
| RS06 后侧延长件 |  | 2-RSM2-STATOR-2.step  | 5052 铝合金 | 2  | CNC  | |
| Link2 左右金属件  |  | 2-LINK-2_3.step | 5052 铝合金 | 2  | CNC  | |
| 上限位 L |  | 2-Upper-Limit_L.stp | 5052 铝合金 | 1  | CNC  | |
| 上限位 R |  | 2-Upper-Limit_R.stp | 5052 铝合金 | 1  | CNC  | |
| 下臂与上臂连接件 L |  | 2-RSM3-ROTATOR-L.step | 5052 铝合金 | 1  | CNC  | |
| 下臂与上臂连接件 R |  | 2-RSM3-ROTATOR-R.step | 5052 铝合金 | 1  | CNC  | |
| Link3 左侧金属件  |  | 2-LINK-3_4-L.step | 5052 铝合金 | 1  | CNC  | |
| Link3 右侧金属件  |  | 2-LINK-3_4-R.step | 5052 铝合金 | 1  | CNC  | |
| Link3 左右连接件  |  | 2-SPACE-UP-2.step | 5052 铝合金 | 1  | CNC  | |
| 电机 4–7 线缆固定件 |  | 1-O-CLIP.step | 5052 铝合金 | 4  | CNC  | Seeed Studio 出货版本中，该部件会作为一个与其他部件集成的 CNC 金属件生产，因此制造成本较高。如果自行复现硬件，可以使用 ABS 材料 3D 打印该部件，并在红色箭头标记的位置安装 M2 螺母。 |
| 电机4背部轴承座 |  | 2-Motor_Back_Spacer.step |  5052 铝合金  | 1 | CNC |  |
| Link4-5_L |  | 2-LINK-4_5-L.step | 5052 铝合金 | 1  | CNC  | |
| Link4-5_R |  | 2-LINK-4_5-R.step | 5052 铝合金 | 1  | CNC  | |
| Link5 |  | 2-RSM5-STATOR.step | 5052 铝合金 | 1  | CNC  | |
| 手腕连接件 A |  | 2-RSM6-RORATOR-1.step | 5052 铝合金 | 1  | CNC  | |
| 手腕连接件 B |  | 2-RSM6-RORATOR-2.step | 5052 铝合金 | 1  | CNC  | |
| 夹爪连接件 A |  | 2-M6-ROTOR.step | 5052 铝合金 | 1  | CNC  | |
| 夹爪连接件 B |  | 2-M7-STATOR.step | 5052 铝合金 | 1  | CNC  | |
| 夹爪滑块金属支架 |  | 2-RAIL-BASE-1.step | 5052 铝合金 | 1  | CNC  | 可使用高填充率 ABS 进行 3D 打印，但不建议长期使用 |
| 滑块到夹爪延长件 |  | 2-SLIDER-FIX.step | 5052 铝合金 | 2  | CNC  | |
| 齿条 |  | 2-RACK-1M.step | 5052 铝合金 | 2  | CNC  | |

### 🧩 加工规格

* 关键尺寸公差：±0.02 mm，GB/T1840-M
* 表面处理：阳极氧化 / 喷砂
* 推荐配合方式：H7 / 过盈配合

---

## 🛒 采购件（标准件）

> [!WARNING]
> 由于用户需要自行组装并拧紧螺丝，因此本 BOM 选择了标准内六角螺丝。长时间运行后，螺丝可能会松动，从而影响机械臂精度。因此，建议额外购买热熔胶，用于对各关节处螺丝进行螺纹锁固。
>
> 如果你有电钻或类似工具，也可以选择购买弹簧垫圈或防松螺丝。不过，使用电动螺丝刀时 **务必使用最低扭矩档位**，避免滑牙，否则可能造成不可逆损坏。
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

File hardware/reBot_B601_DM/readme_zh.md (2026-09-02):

# 🤖 reBot DevArm 开源硬件说明

<p align="center">
  reBot-DevArm Banner
</p>
<p align="center">
  <strong>
    <a href="./readme_zh.md">简体中文</a> &nbsp;|&nbsp;
    <a href="./readme.md">English</a> &nbsp;|&nbsp;
    <a href="./readme_jp.md">日本語</a>&nbsp;|&nbsp;
    <a href="./readme_fr.md">français</a>&nbsp;|&nbsp;
    <a href="./readme_es.md">Español</a>
  </strong>
</p>

|  日期 | 版本号 | 文件名 | 更新日志 |
|---|---|---|---|
|  3.31.2026 | v1.0 |  reBot_B601_DM_v1.0_20260331.step  | 第一次上传 |
|  4.25.2026 | v1.1 |  reBot_B601_DM_v1.1_20260425.step  | 增加了末端3个关节电机的线束卡口`Cable Restraint`，防松防脱落。修复了第一个关节型号`由4310改为4340P`。底部增加了CNC件`02_Base_Reinforcement_Part.step`加强底部强度。增加了线束卡扣。 |

当前BOM为reBot Arm B601 DM机械臂清单，所使用的是Damiao43系列电机，另一款reBot Arm B601 RS机械臂所使用的是RobStride电机，[清单请看这里](../reBot_B601_RS/README.md)

# 📦 文件结构
*   `3D_Printed_Parts/`: 所有3D打印文件的Step。
*   `Metal_Parts/`: 所有金属加工文件的Step。
*   `Purchased_Parts/`: 所有购买件的Step。
*   `reBot_B601_DM_v1.1_20260415step`: 机械臂整体装配文件。

# 📊 物料清单（BOM）

> [!WARNING]
>特此申明，公布的BOM并非代表Seeed出货的最终版本，此`v1.1`开源版本是方便开发者并能够尽可能减少成本自己加工复现的版本,减少了一些不必要的细节开支，Seeed 最终出货版本会有金属镭雕防呆提示，部分3D打印件为了耐久会替换为金属件，根据金属加工厂的误差做间隙和加工精度调整（精度和成本的平衡），线束的特殊定制（例如增加编制绳保护）等需要增加一定成本的细节优化，但是结构构型相同。

---

## 🖨️ 3D打印件

|  零件描述 | 图片 | 文件名 | 材料 | 数量 | 备注 |
|---|---|---|---|---|---|
| 机械臂底座平台 |  | `01_BASE_Plate.step` | 拓竹 ABS 黑色  |  1 |  0.4喷嘴 0.2层高 30%填充 |
| 机械臂底座 |  | `01_BASE_Link.step` | 拓竹 ABS 黑色  |  1 |  0.4喷嘴 0.2层高 30%填充 |
| 大臂左侧填充 |  | `01_Upper_Arm_Fuller_L.step` | 拓竹 PLA 黑色和绿色  |  1 |  0.4喷嘴 0.2层高 15%填充 |
| 大臂右侧填充 |  | `01_Upper_Arm_Fuller_R.step` | 拓竹 PLA 黑色和绿色 |  1 |  0.4喷嘴 0.2层高 15%填充 |
| 大臂中间填充 |  | `01_Upper_Arm_Fuller_M.step` | 拓竹 ABS 黑色  |  1 |  0.4喷嘴 0.2层高 30%填充 |
| 大臂水平限位块 |  | `01_Upper_Arm_Limit.step` |拓竹 ABS 黑色  |  1 |  0.4喷嘴 0.2层高 30%填充 |
| 机械臂提手 |  | `01_Arm_Handle.step` |拓竹 ABS 黑色  |  1 |  0.4喷嘴 0.2层高 30%填充 |
| 小臂左侧填充 |  | `01_Lower_Arm_Filler_L.step` |拓竹 PLA 黑色和绿色  |  1 |  0.4喷嘴 0.2层高 15%填充 |
| 小臂右侧填充 |  | `01_Lower_Arm_Filler_R.step` |拓竹 PLA 黑色和绿色  |  1 |  0.4喷嘴 0.2层高 15%填充 |
| 小臂中间填充 |  | `01_Lower_Arm_Filler_M.step` |拓竹 ABS 黑色  |  1 |  0.4喷嘴 0.2层高 30%填充 |
| 大臂装饰 |  | `01_Upper_Arm_Cover.step` |拓竹 PLA 绿色  |  1 |  0.4喷嘴 0.2层高 15%填充 |
| 小臂装饰 |  | `01_Lower_Arm_Cover.step` |拓竹 PLA 绿色  |  1 |  0.4喷嘴 0.2层高 15%填充 |
| 5号电机保护盖 |  | `01_Motor_Cover.step` |拓竹 ABS 黑色  |  1 |  0.4喷嘴 0.2层高 30%填充 |
| 夹爪水平限位 |  | `01_Lower_Arm_Limit.step` |  拓竹 PLA 绿色  |  1 |  0.4喷嘴 0.2层高 15%填充 |
| 夹爪滑块填充支架 |  | `01-Rail-Bracket.step` |  拓竹 PLA 绿色  |  1 |  0.4喷嘴 0.2层高 15%填充 |
| 夹爪  |  | `01_Finger.step` |  拓竹 ABS 黑色  |  2 |  0.4喷嘴 0.2层高 45%填充 |
| 电机5线束约束加固 |  | `01_Joint5_Cable Restraint_A.step` |  拓竹 PLA 绿色  |  1 |  0.4喷嘴 0.2层高 15%填充 |
| 电机6和7线束约束加固  |  | `01_Joint6_7_Cable Restraint_A.step` |  拓竹 ABS 黑色  |  2 |  0.4喷嘴 0.2层高 30%填充 |
| 电机6和7线束约束加固  |  | `01_Joint6_7_Cable Restraint_B.step` |  拓竹 ABS 黑色  |  2 |  0.4喷嘴 0.2层高 30%填充 |
| | `参考价格` | 平均**350RMB**  | |  | 因打印材料价格、和工厂打印时长不同，价格略有浮动|  |  

长期使用过程中拖拽线束1会磨损电机接口导致接触不良，你可以打印如下文件降低这个风险。
|  零件描述 | 图片 | 文件名 | 材料 | 数量 | 备注 |
|---|---|---|---|---|---|
| 电机1两个面的线束卡扣  |  | `DM_Motor1_wiring_harness_clip.stp` |  拓竹 ABS 黑色  |  2 |  0.4喷嘴 0.2层高 30%填充 |

##  📷兼容的相机支架

|  零件描述 | 图片 | 文件名 | 材料 | 数量 | 备注 |
|---|---|---|---|---|---|
| Orbbec Gemini2相机 |  | [`D435_Gemini2_Mount.step`](./3D_Printed_Parts/D435_Gemini2_Mount.step) | 拓竹 ABS 黑色  |  1 |  0.4喷嘴 0.2层高 30%填充 |

### 🧩 打印建议
- 层高：0.2 mm
- 喷嘴：0.4 mm
- 支撑：按需添加  
- 材料：需要受到高温和一定力的部分使用的是ABS材料并且填充在30%~80%，也可以改为尼龙 / 碳纤增强材料，外观装饰件使用的是PLA，填充15%。
- 受力件建议材料：

---

## 🔩 金属加工件

> [!WARNING]
> 这里部分可用3D打印替代的零件已在备注中表明，可极大进一步降低成本开支。

| 零件描述 | 图片 | 文件名 | 材料 | 数量 |  加工工艺 |  备注 |
|---|---|---|---|---|---|---|
| 电机1轴承安装位 |  | `02_Base_Reinforcement_Part.step` |铝合金5052  | 1 | CNC| 可用3D打印ABS，增加填充来降低成本  | 
| 电机1旋转轴 |  | `02_Arm_Yaw_Limit.step` |铝合金5052  | 1 | CNC| 增加了航向角的运动限位 | 
| 电机2-5的正面垫片 |  | `02_Motor_Front_Spacer.step` |铝合金5052  | 4 | CNC| 可用3D打印ABS，30%填充来降低成本 | 
| 电机2-4的背面垫片 |  | `02_Motor_Back_Spacer.step` |铝合金5052  | 3 | CNC|  | 
| 电机2-4的背面法兰 |  | `02_FLANGE.step` |铝合金5052  | 3 | CNC| | 
| 腕部电机5底座 |  | `02_Wrist_Bracket.step` |铝合金5052  | 1 | CNC|  | 
| 爪子连接器A |  | `02_Gripper_Connector_A.step` |铝合金5052  | 1 | CNC|  | 
| 爪子连接器B |  | `02_Gripper_Connector_B.step` |铝合金5052  | 1 | CNC|  | 
| 爪子滑块金属支架 |  | `02_Slider_Bracket.step` |铝合金5052  | 1 | CNC|  可用3D打印ABS，增加填充来降低成本，但是不推荐长期使用 | 
| 滑块与爪子连接器 |  | `02_Slider_Extension.step` |铝合金5052  | 2 | CNC| | 
| 大小臂关节连接件左 |  | `02_Lower_Upper_Link_L.step` |铝合金5052  | 1 | CNC|  | 
| 大小臂关节连接件右 |  | `02_Lower_Upper_Link_R.step` |铝合金5052  | 1 | CNC|  | 
| 小臂与腕关节连接件左 |  | `02_Lower_Wrist_Link_L.step` |铝合金5052  | 1 | CNC|  | 
| 小臂与腕关节连接件右 |  | `02_Lower_Wrist_Link_R.step` |铝合金5052  | 1 | CNC| | 
| 齿轮连接器  |  | `02_Gear_Connector.step` |  铝合金5052  |  1 |  CNC |  |
| 齿条  |  | `02_Rack.step` |  铝合金5052  |  2 |  CNC |  |
| 连杆1  |  | `03_Link1.step` |  铝合金5052  |  1 |  CNC+钣金 | |
| 连杆2  |  | `03_Link2.step` |  铝合金5052  |  2 |  CNC+钣金 |  |
| 连杆3左  |  | `03_Link3_L.step` |  铝合金5052  |  1 |  CNC+钣金 |  |
| 连杆3右  |  | `03_Link3_R.step` |  铝合金5052  |  1 |  CNC+钣金 |  |
| 连杆5  |  | `03_Link5.step` |  铝合金5052  |  1 |  CNC+钣金 |  |
| 多家市场参考价格  |  | 平均**1500RMB**  | |  | 因铝5052成本浮动、加工精度要求、工厂交期等，价格略有浮动|  |  

### 🧩 加工说明
- 关键尺寸公差：±0.02 mm GB/T1840-M；
- 表面处理：阳极氧化 / 喷砂   
- 配合件建议采用 H7 / 过盈配合  

---
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

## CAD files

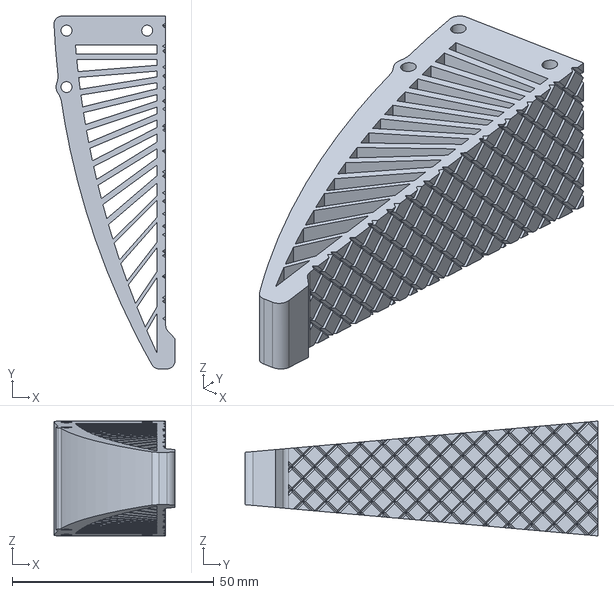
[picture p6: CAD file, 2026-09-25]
hardware/reBot_B601_DM/3D_Printed_Parts/Soft_Gripper_Finger.step
30.0 x 87.5 x 28.5 mm

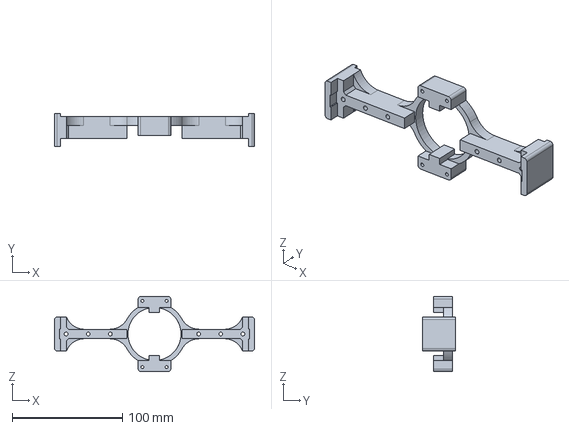
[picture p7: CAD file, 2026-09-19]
hardware/reBot_B601_RS/3D_Printed_Parts/01_Rail_Bracket.step
181.1 x 30.0 x 68.1 mm

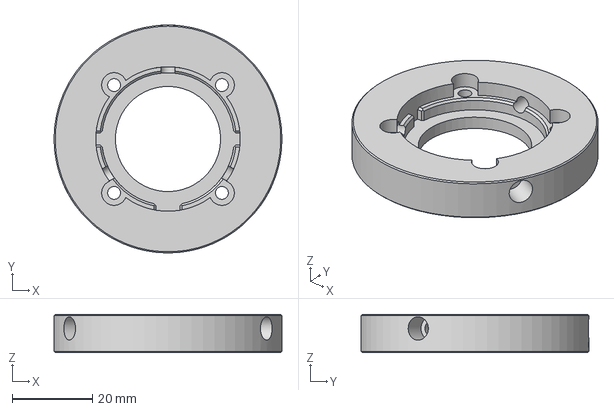
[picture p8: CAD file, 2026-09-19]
hardware/reBot_B601_RS/Metal_Parts/2-M7-STATOR.step
56.8 x 56.8 x 9.50 mm

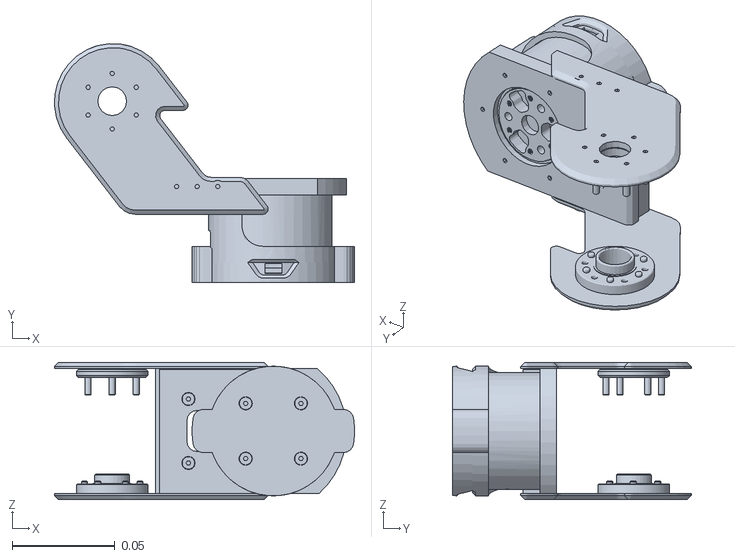
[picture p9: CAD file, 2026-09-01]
Rebot_Arm_description/DM/meshes/collision/link4.STL
0.146 x 0.116 x 0.0668

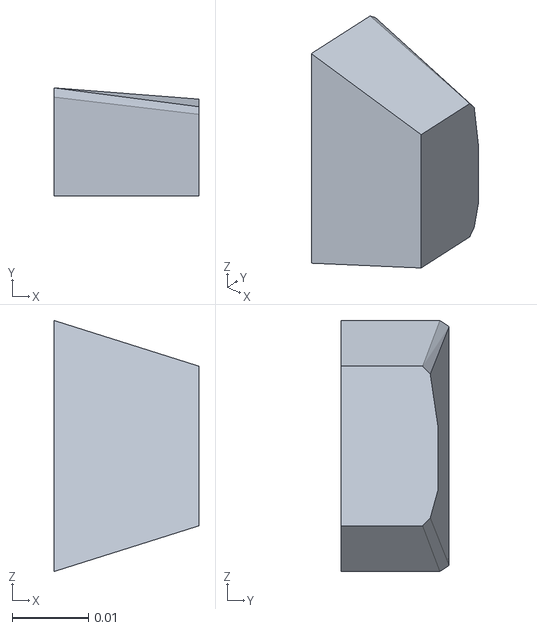
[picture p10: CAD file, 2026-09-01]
Rebot_Arm_description/DM/meshes/mujoco_collision/left_finger_mid.stl
0.019 x 0.0142 x 0.033

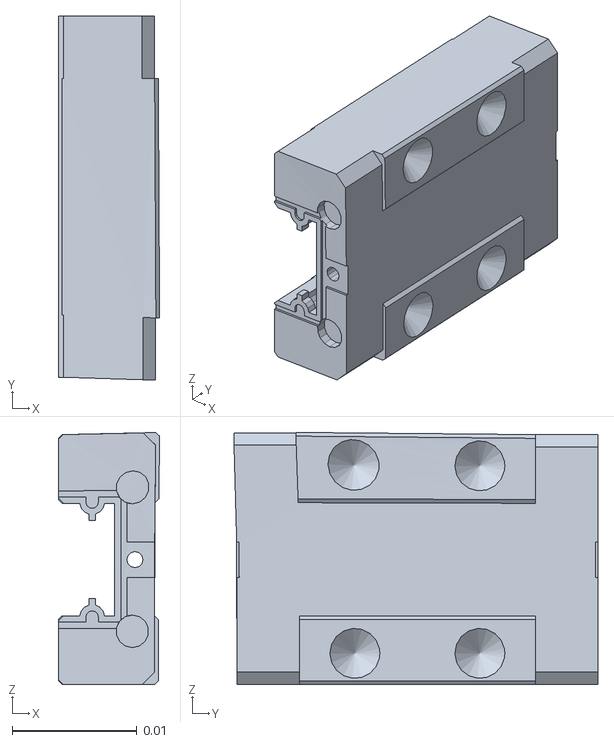
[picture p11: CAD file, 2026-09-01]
Rebot_Arm_description/DM/meshes/shared/colored_right_finger_travel_stop_yellow.stl
0.0081 x 0.0291 x 0.0202

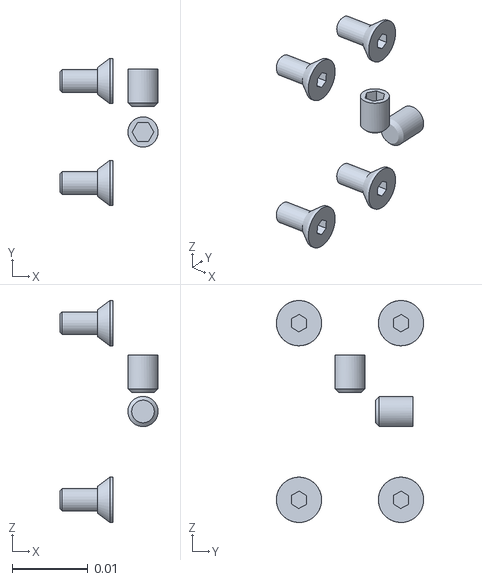
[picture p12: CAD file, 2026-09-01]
Rebot_Arm_description/DM/meshes/visual/colored_gripper_base_hardware_black.stl
0.013 x 0.0195 x 0.0294

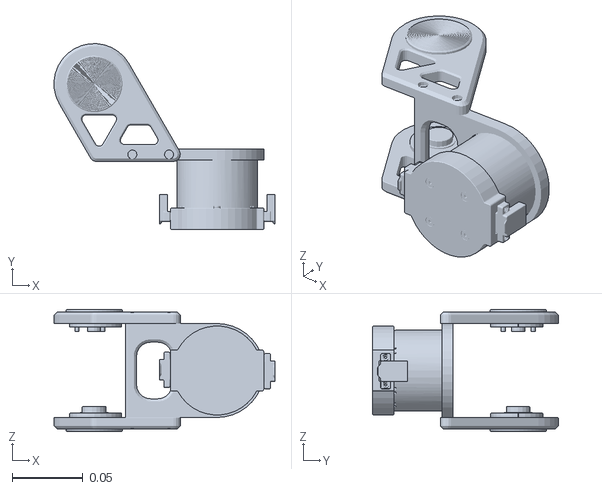
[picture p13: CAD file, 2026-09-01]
Rebot_Arm_description/RS/meshes/shared/link4.STL
0.156 x 0.131 x 0.0865

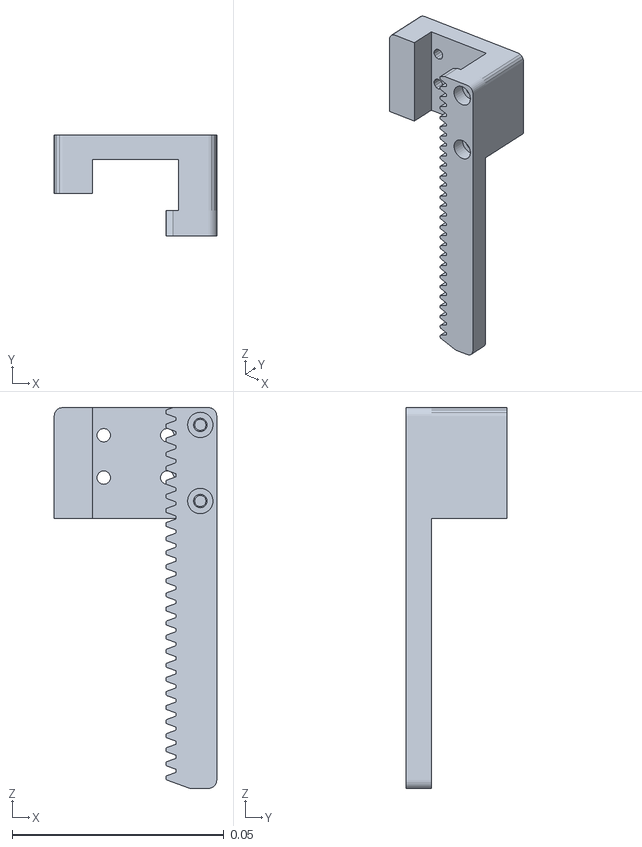
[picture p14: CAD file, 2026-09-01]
Rebot_Arm_description/RS/meshes/visual/cnc_right.STL
0.0384 x 0.0238 x 0.09

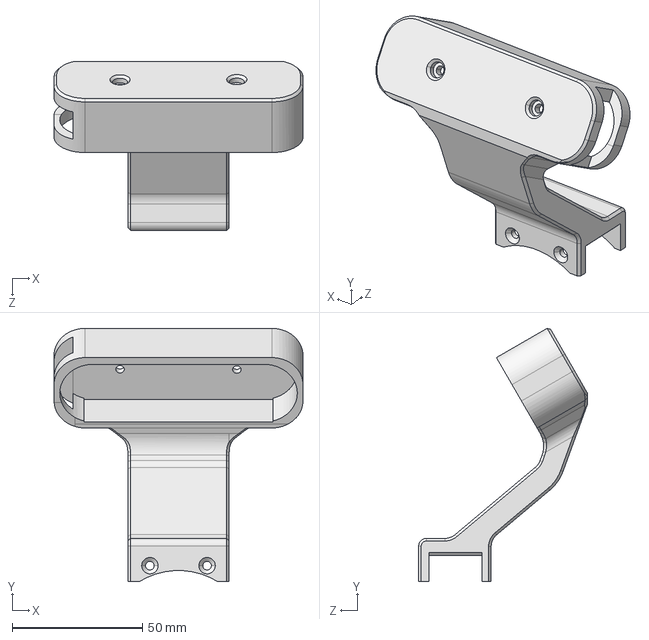
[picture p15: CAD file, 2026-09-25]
hardware/reBot_B601_DM/3D_Printed_Parts/D435_Gemini2_Mount.step
95.8 x 97.4 x 64.9 mm

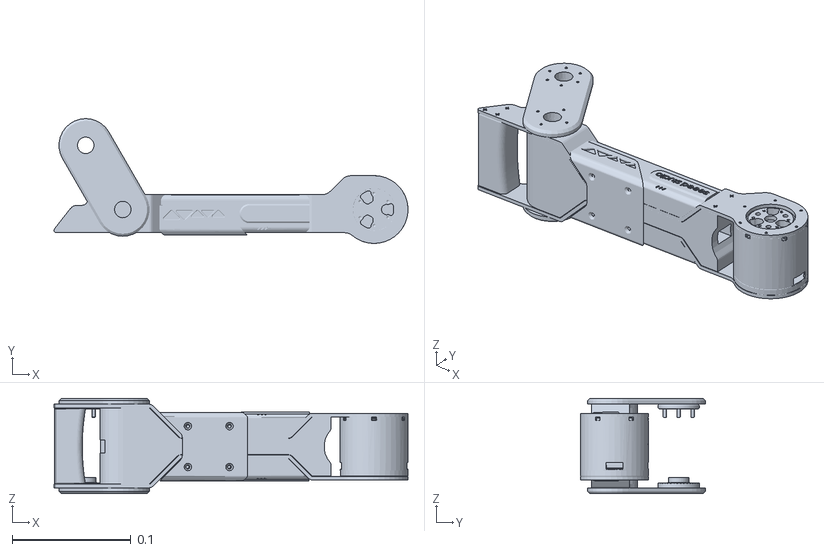
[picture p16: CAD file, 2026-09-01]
Rebot_Arm_description/DM/meshes/collision/link3.STL
0.298 x 0.105 x 0.0802

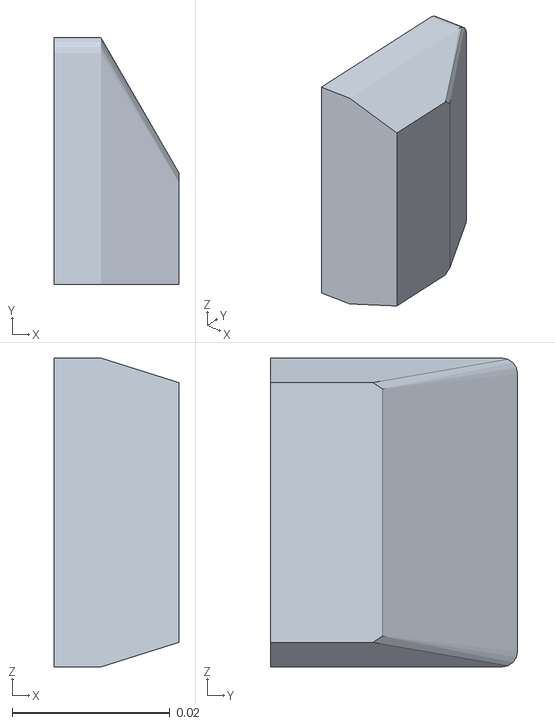
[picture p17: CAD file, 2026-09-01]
Rebot_Arm_description/DM/meshes/mujoco_collision/left_finger_rear.stl
0.0158 x 0.0314 x 0.0392

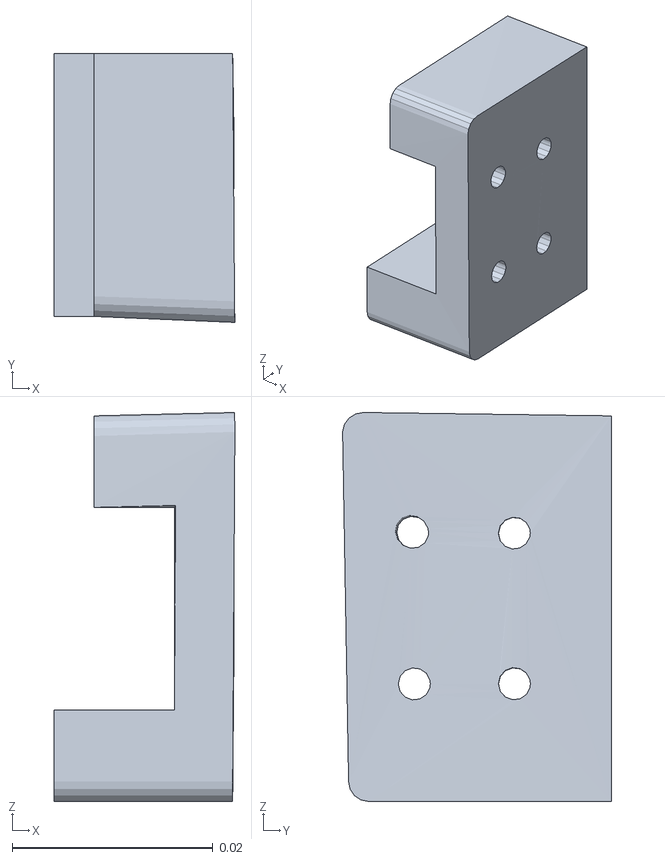
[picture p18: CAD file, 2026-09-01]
Rebot_Arm_description/DM/meshes/shared/colored_right_finger_carriage_grey.stl
0.018 x 0.0268 x 0.0388

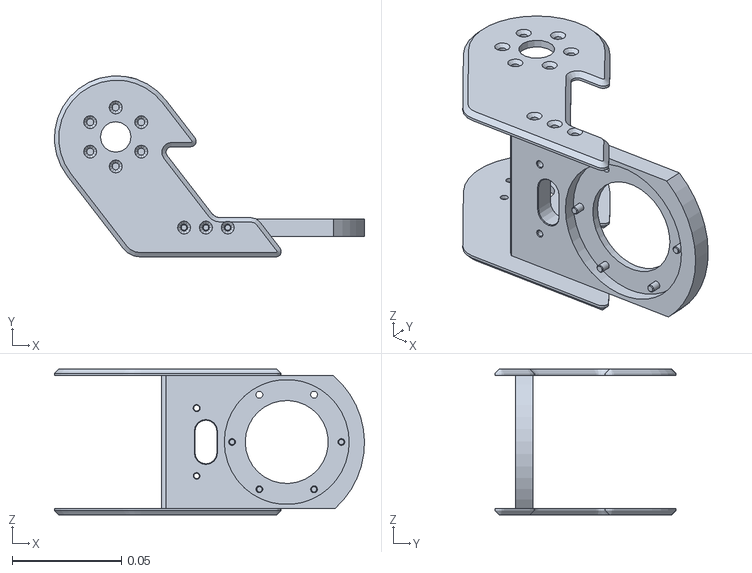
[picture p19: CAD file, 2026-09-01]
Rebot_Arm_description/DM/meshes/visual/colored_link4_anodized_grey.stl
0.142 x 0.0829 x 0.0668

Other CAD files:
Rebot_Arm_description/RS/meshes/mujoco_collision/right_finger_rear.stl
Rebot_Arm_description/RS/meshes/shared/link1.STL
Rebot_Arm_description/RS/meshes/visual/pla5_green.STL
Rebot_Arm_description/DM/meshes/collision/base_link.STL
Rebot_Arm_description/DM/meshes/collision/gripper_base.stl
Rebot_Arm_description/DM/meshes/collision/left_finger.stl
Rebot_Arm_description/DM/meshes/collision/link1.STL
Rebot_Arm_description/DM/meshes/collision/link2.STL
Rebot_Arm_description/DM/meshes/collision/link5.STL
Rebot_Arm_description/DM/meshes/collision/link6.STL
Rebot_Arm_description/DM/meshes/collision/right_finger.stl
Rebot_Arm_description/DM/meshes/mujoco_collision/left_finger_front.stl
Rebot_Arm_description/DM/meshes/mujoco_collision/right_finger_front.stl
Rebot_Arm_description/DM/meshes/mujoco_collision/right_finger_mid.stl
Rebot_Arm_description/DM/meshes/mujoco_collision/right_finger_rear.stl
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

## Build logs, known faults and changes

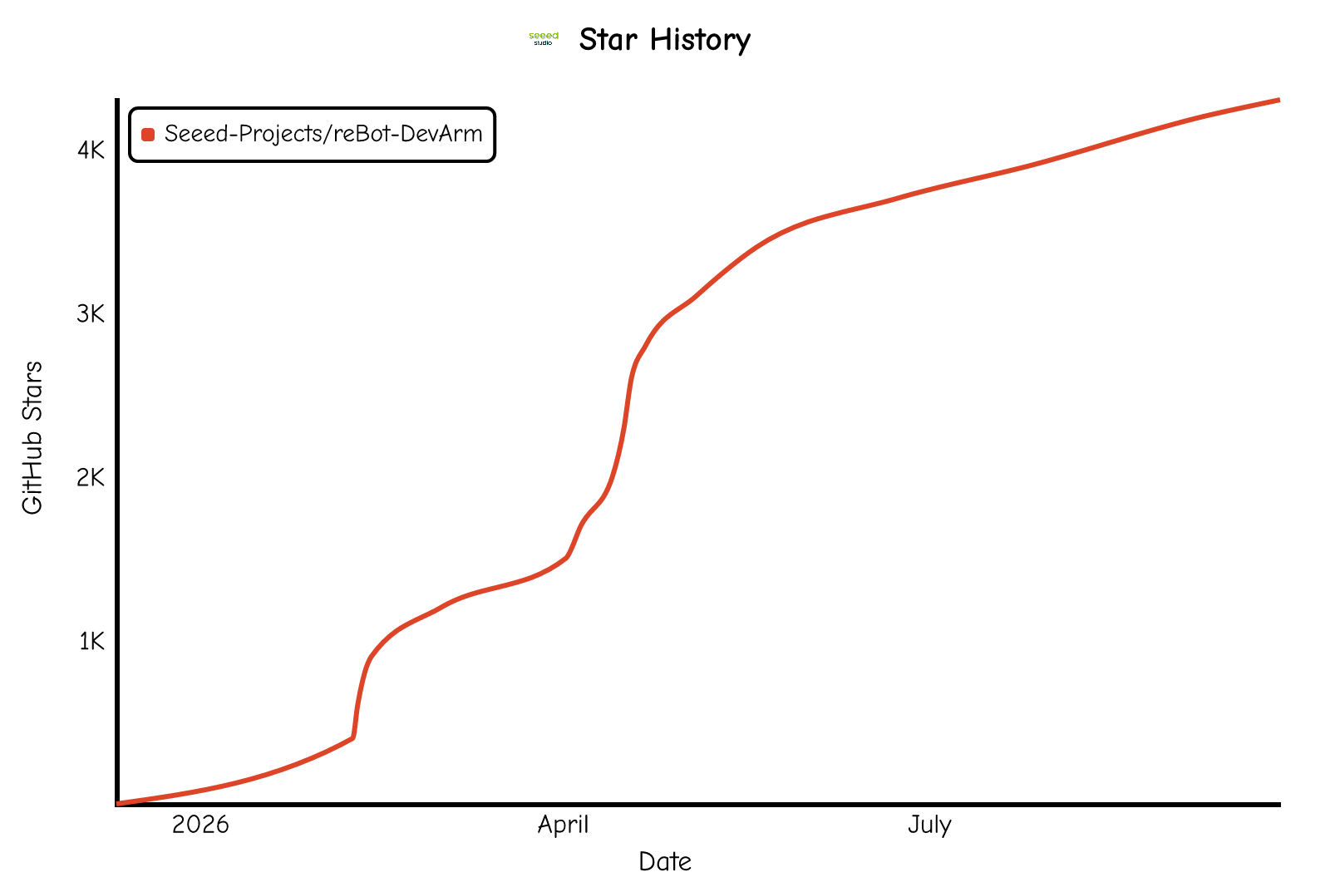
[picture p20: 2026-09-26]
assets/star-history/star-history.png

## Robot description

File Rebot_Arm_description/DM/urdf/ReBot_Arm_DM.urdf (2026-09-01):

<?xml version='1.0' encoding='utf-8'?>
<robot name="ReBot_Arm_DM">
  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
  <link name="base_link">
    <inertial>
      <origin xyz="-7.849E-06 -1.1531E-06 0.029841" rpy="0 0 0" />
      <mass value="0.83660000" />
      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
    </inertial>
    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
  </link>
  <link name="link1">
    <inertial>
      <origin xyz="0.000113614552951627 -0.000616319527051323 0.0236476372671394" rpy="0 0 0" />
      <mass value="0.16130000" />
      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
    </inertial>
    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
  </link>
  <joint name="joint1" type="revolute">
    <origin xyz="-8.416E-05 0 0.08465" rpy="0 0 0" />
    <parent link="base_link" />
    <child link="link1" />
    <axis xyz="0 0 1" />
    <limit lower="-2.8" upper="2.8" effort="27" velocity="50" />
  </joint>
  <link name="link2">
    <inertial>
      <origin xyz="-0.13225622308888 -0.0030617036386309 -0.0308306967030205" rpy="0 0 0" />
      <mass value="1.32660000" />
      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
    </inertial>
    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
  </link>
  <joint name="joint2" type="revolute">
    <origin xyz="0.020084 0.031625 0.05555" rpy="-1.5708 0 0" />
    <parent link="link1" />
    <child link="link2" />
    <axis xyz="0 0 -1" />
    <limit lower="-3.14" upper="0" effort="27" velocity="50" />
  </joint>
  <link name="link3">
    <inertial>
      <origin xyz="0.121040035791843 -0.0536211076627949 -0.0310137854608077" rpy="0 0 0" />
      <mass value="0.83530000" />
      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
    </inertial>
    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
  </link>
  <joint name="joint3" type="revolute">
    <origin xyz="-0.264 0 0" rpy="0 0 0" />
    <parent link="link2" />
    <child link="link3" />
    <axis xyz="0 0 1" />
    <limit lower="-3.14" upper="0" effort="27" velocity="50" />
  </joint>
  <link name="link4">
    <inertial>
      <origin xyz="0.0608200956293136 -0.0511711906613122 -0.030299458623927" rpy="0 0 0" />
      <mass value="0.52000000" />
      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
    </inertial>
    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
  </link>
  <joint name="joint4" type="revolute">
    <origin xyz="0.2426 -0.054 -0.001625" rpy="0 0 0" />
    <parent link="link3" />
    <child link="link4" />
    <axis xyz="0 0 1" />
    <limit lower="-1.87" upper="1.57" effort="7" velocity="200" />
  </joint>
  <link name="link5">
    <inertial>
      <origin xyz="-0.00502802058982517 1.73866206692364E-06 0.0386233236326755" rpy="0 0 0" />
      <mass value="0.38300000" />
      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
    </inertial>
    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
  </link>
  <joint name="joint5" type="revolute">
    <origin xyz="0.078308 -0.0375 -0.03" rpy="-1.5708 0 0" />
    <parent link="link4" />
    <child link="link5" />
    <axis xyz="0 0 1" />
    <limit lower="-1.57" upper="1.57" effort="7" velocity="200" />
  </joint>
  <link name="link6">
    <inertial>
      <origin xyz="3.76418727127126E-06 -0.000100908819946677 0.0253308606425965" rpy="0 0 0" />
      <mass value="0.36630000" />
      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
    </inertial>
    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
  </link>
  <joint name="joint6" type="revolute">
    <origin xyz="0.028008 0 0.04" rpy="0 1.5708 0" />
    <parent link="link5" />
    <child link="link6" />
    <axis xyz="0 0 1" />
    <limit lower="-3.14" upper="3.14" effort="7" velocity="200" />
  </joint>
  <link name="end_link">
    <inertial>
      <origin xyz="-0.0737654295815033 -9.5080995865868E-06 7.04327840286845E-06" rpy="0 0 0" />
      <mass value="0.5000000" />
      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
    </inertial>
    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
  </link>
  <joint name="end_joint" type="fixed">
    <origin xyz="0 0 0.15539" rpy="0 -1.5708 3.1415" />
    <parent link="link6" />
    <child link="end_link" />
    <axis xyz="0 0 0" />
  </joint>
  <link name="finger_left_link">
    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
  </link>
  <joint name="finger_left" type="prismatic">
    <origin xyz="0 0 0" rpy="0 0 0" />
    <parent link="end_link" />
    <child link="finger_left_link" />
    <axis xyz="0 1 0" />
    <limit lower="0" upper="0.05" effort="8" velocity="0.08" />
  </joint>
  <link name="finger_right_link">
    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
  </link>
  <joint name="finger_right" type="prismatic">
    <origin xyz="0 0 0" rpy="0 0 0" />
    <parent link="end_link" />
    <child link="finger_right_link" />
    <axis xyz="0 1 0" />
    <limit lower="-0.05" upper="0" effort="8" velocity="0.08" />
    <mimic joint="finger_left" multiplier="-1" offset="0" />
  </joint>
</robot>

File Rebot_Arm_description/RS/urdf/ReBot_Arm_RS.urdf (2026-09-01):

<?xml version="1.0" encoding="utf-8"?>
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
<robot name="ReBot_Arm_RS">
  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
  <link name="base_link">
    <inertial>
      <origin xyz="2.87641888266442E-06 -0.000122302488725115 0.0243376121934547" rpy="0 0 0" />
      <mass value="1.1774" />
      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
    </inertial>
    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
  </link>
  <link name="link1">
    <inertial>
      <origin xyz="0.00817652280320541 0.00122584211922395 0.0331419658967293" rpy="0 0 0" />
      <mass value="0.4655" />
      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
    </inertial>
    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
  </link>
  <joint name="joint1" type="revolute">
    <origin xyz="-0.00034283 -0.00098683 0.075" rpy="0 0 0" />
    <parent link="base_link" />
    <child link="link1" />
    <axis xyz="0 0 -1" />
    <limit lower="-2.8" upper="2.8" effort="36" velocity="50" />
  </joint>
  <link name="link2">
    <inertial>
      <origin xyz="-0.117864812717456 -0.00342226413942967 -0.0271551938501484" rpy="0 0 0" />
      <mass value="1.552" />
      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
    </inertial>
    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
  </link>
  <joint name="joint2" type="revolute">
    <origin xyz="0.020343 0.027237 0.07" rpy="-1.5708 0 0" />
    <parent link="link1" />
    <child link="link2" />
    <axis xyz="0 0 1" />
    <limit lower="0" upper="3.14" effort="36" velocity="50" />
  </joint>
  <link name="link3">
    <inertial>
      <origin xyz="0.103427154487799 -0.0664137912104635 -0.0271068687716704" rpy="0 0 0" />
      <mass value="1.252" />
      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
    </inertial>
    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
  </link>
  <joint name="joint3" type="revolute">
    <origin xyz="-0.236 0 0" rpy="0 0 0" />
    <parent link="link2" />
    <child link="link3" />
    <axis xyz="0 0 -1" />
    <limit lower="0" upper="3.14" effort="36" velocity="50" />
  </joint>
  <link name="link4">
    <inertial>
      <origin xyz="0.0475544540775559 -0.0441113470158517 -0.0314111924918381" rpy="0 0 0" />
      <mass value="0.46" />
      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
    </inertial>
    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
  </link>
  <joint name="joint4" type="revolute">
    <origin xyz="0.228 -0.072746 0.0045" rpy="0 0 0" />
    <parent link="link3" />
    <child link="link4" />
    <axis xyz="0 0 -1" />
    <limit lower="-1.57" upper="1.57" effort="14" velocity="40" />
  </joint>
  <link name="link5">
    <inertial>
      <origin xyz="0.0114400622356175 4.7907739316217E-06 0.0380487481818926" rpy="0 0 0" />
      <mass value="0.20120457182895" />
      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
    </inertial>
    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
  </link>
  <joint name="joint5" type="revolute">
    <origin xyz="0.087 -0.048 -0.03075" rpy="-1.5708 0 0" />
    <parent link="link4" />
    <child link="link5" />
    <axis xyz="0 0 -1" />
    <limit lower="-1.57" upper="1.57" effort="14" velocity="40" />
  </joint>
  <link name="link6">
    <inertial>
      <origin xyz="1.80196022567525E-05 2.48334592051007E-08 0.00434805764057547" rpy="0 0 0" />
      <mass value="0.1" />
      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
    </inertial>
    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
  </link>
  <joint name="joint6" type="revolute">
    <origin xyz="0.0365 0 0.048" rpy="0 1.5708 0" />
    <parent link="link5" />
    <child link="link6" />
    <axis xyz="0 0 -1" />
    <limit lower="-3.14" upper="3.14" effort="14" velocity="40" />
  </joint>
  <link name="gripper_end">
    <inertial>
      <origin xyz="-0.112751692515958 0.000128443070436966 -5.72602449749882E-06" rpy="0 0 0" />
      <mass value="0.65" />
      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
    </inertial>
    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
  </link>
  <joint name="j_gripper_end" type="fixed">
    <origin xyz="0 0 0.16621" rpy="3.1416 -1.5708 0" />
    <parent link="link6" />
    <child link="gripper_end" />
    <axis xyz="0 0 0" />
  </joint>
  <link name="gripper_left">
    <inertial>
      <origin xyz="-0.00218008703135955 0.0187090355934181 0.00932188568692145" rpy="0 0 0" />
      <mass value="0.0752" />
      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
    </inertial>
    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
  </link>
  <joint name="gripper_joint1" type="prismatic">
    <origin xyz="-0.041939 -7.3385E-05 0" rpy="1.5708 -1.5708 0" />
    <parent link="gripper_end" />
    <child link="gripper_left" />
    <axis xyz="0 0 1" />
    <limit lower="0" upper="0.05" effort="500" velocity="10" />
  </joint>
  <link name="gripper_right">
    <inertial>
      <origin xyz="0.00218008703135955 -0.018709035593418 0.00932188568692151" rpy="0 0 0" />
      <mass value="0.0752" />
      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
    </inertial>
    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
  </link>
  <joint name="gripper_joint2" type="prismatic">
    <origin xyz="-0.041939 7.3385E-05 0" rpy="-1.5708 -1.5708 0" />
    <parent link="gripper_end" />
    <child link="gripper_right" />
    <axis xyz="0 0 1" />
    <limit lower="0" upper="0.0715" effort="500" velocity="10" />
  </joint>
</robot>

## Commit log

2026-08-30 feat(hardware): revise D405/Gemini 305 mount to 30 degrees
    [D405_305_Mount.step]
2026-09-01 docs: add reusable ReBot Arm descriptions
    [ReBot_Arm_DM.urdf, ReBot_Arm_RS.csv, ReBot_Arm_RS.urdf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]
2026-09-03 docs: link Star Arm 102-LD purchase in optional hardware tables
    Replace coming-soon placeholders with the Seeed store URL across README languages.
2026-09-18 update camera mount
    [D405_305_Mount.step, D435_Gemini2_Mount.step, D455f_Mount.step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]
2026-09-19 update some mental parts
    [01_Rail_Bracket.step, 2-M7-STATOR.step]
2026-09-25 add new soft gripper and camera mount
    [D405_305_Mount.step, D435_Gemini2_Mount.step, Soft_Gripper_Finger.step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]

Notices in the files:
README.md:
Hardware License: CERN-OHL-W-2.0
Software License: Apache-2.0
